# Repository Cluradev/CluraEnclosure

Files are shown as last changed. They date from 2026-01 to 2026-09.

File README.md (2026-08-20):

# CluraEnclosure

**The Clura Enclosure** is the 100% open-source, modular, and smart enclosure designed for desktop 3D printers. Developed with a focus on safety and air quality, it incorporates active filtration and smart sensors to enhance your 3D printing experience.

[Discord Community](https://discord.gg/dJDUmdvcgZ)

Clura Enclosure

## Why We Built It

The project started with me (Fabrizio), an aerospace engineering student who wanted to print in his room without compromising his safety. In fact, it is widely documented that most 3D printer filaments emit VOCs and particulate matter, which can be harmful to health. I searched for a smart, affordable, open-source enclosure but couldn't find one, so I decided to build my own. 18 months of hard work later, here we are!

## Kits

Kickstarter orders are being fulfilled. Future kit batches are being planned, but nothing is finalized yet.

You can still build the enclosure today without waiting on us. Everything here is open source and the [Bill of Materials](Documentation/README.md) lists every part with soemtimes supplier links.

The original campaign page is still up for reference: [Kickstarter](https://www.kickstarter.com/projects/clura/enclosure)

## Documentation

All project documentation, including assembly manuals and Bills of Materials (BOM), will also be published on **CluraDocs**. If you're looking to assemble your own Clura Enclosure, that is the place to go. Note: CluraDocs is still a work in progress, we are always working on improving it. If you have any suggestions or feedback, please let us know!

Check it out here: [CluraDocs](https://docs.clura.dev)

## Key Features

- **Safety & Air Quality:** Dual-layer HEPA and carbon filtration system designed to capture VOCs and UFPs.
- **Smart Controls:** Integrated 4.3" touchscreen for real-time monitoring of temperature, humidity, and air quality.
- **Modular Design:** Fully customizable hardware and software modules.
- **Open Source:** 100% open source CAD files, firmware, and guides.

Clura Enclosure Features

## Repository Structure

- `Documentation/`: Assembly manual and BOM.
- `Firmware/`: Firmware for the screen and the mainboard, plus the SD card files.
- `CAD/`: STEP models of the full enclosure, one per size (PE1, BE1, ME1).
- `PCBs/`: KiCad 9 sources for the mainboard and the sensorboard.
- `Production/`: Ready-to-use production files (laser cutting, extrusions, metal plates, PCB gerbers).
- `3D Printable Files/`: The `.3mf` files you print yourself.

In each folder there is a readme file with more info.

> For the printable parts, [CluraDocs](https://docs.clura.dev/the-build/preparations/printed-parts) has a picker that works out exactly which files and quantities your build needs.

## License

Every file in this repository is released under the **CC BY-NC (Creative Commons Attribution-NonCommercial)** license. 

For more details on the reasoning behind this choice, you can read our blog post: [The License - Clura Blog](https://www.clura.dev/blog/the-license)

---
*For more information, visit [clura.dev](https://www.clura.dev).*

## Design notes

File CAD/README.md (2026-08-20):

# CAD Models

Full assembly models for each enclosure are provided as STEP files, one per size. Fusion 360 source files are currently being refined and will be released in the near future.

These are reference models of the complete enclosure. The files you actually fabricate from live elsewhere:

- **`3D Printable Files/`** in the repository root: the `.3mf` files you print
- **`Production/`**: STEP models of every cut extrusion, DXF for the acrylic panels and metal plates, and the PCB gerbers

### Compatibility
- **PE1**: Prusa i3 MK3 / MK4
- **BE1**: Bambu Lab A1, Creality HI, Ender 3 and similar Ender-style printers
- **ME1**: Prusa Mini, Bambu Lab A1 Mini

Models

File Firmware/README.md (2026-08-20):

# Clura Enclosure - Firmware Guide

Welcome to the Clura Enclosure firmware! This guide covers everything you need to flash firmware and customize your enclosure's behavior.

---

## Quick Start

Files contained in this folder:
1. Bootloader_v1Soft - bootloader for the board, allows to easily update the firmware. All boards come pre flashed with this
2. Monitor - main firmware of the application to be flashed with an st link on the board, so if one wishes to not have the bootloader (mainly for testing)
3. MonitorBTL - main firmware of the board, flashed using monitor.bin file
4. Screen UI - contains HMI editable file, and monitorHMI.tft (to be renamed firmware.tft in order to flash the screen)
5. SD Card files - monitor.bin (file to flash the latest firmware), filament.clu (file to edit the filaments on the EEPROM, it's automatically generated by the board), data.clu (allows many parameters of the board to be adjusted, needs to be copied onto the sd card)

### Flashing Firmware

The easiest way to update your Clura Enclosure is using an SD card.

#### Main PCB Update

1. Copy your build to the root of the SD card and **name it exactly `monitor.bin`**
2. Insert the SD card into the main PCB
3. Power on the enclosure
4. Wait for the confirmation message on screen
5. The system will automatically reboot with new firmware

> **The filename matters.** The bootloader only ever looks for `monitor.bin`

The bootloader **checks the image before erasing anything**: it verifies the file
size, reads it end to end, and confirms it looks like real firmware. Only then does it
erase and program, and afterwards it verifies what was written. If any of that fails it
shows the failure page and leaves your existing firmware untouched. `monitor.bin` is deleted only after a
successful, verified update.

#### Screen Update

1. Copy `firmware.tft` to the root of your SD card (this is `monitorHMI.tft` renamed)
2. Insert the SD card into the screen
3. Power on the screen
4. Wait for flashing to complete
5. **Remove the SD card** and power cycle the screen

> **Note**: Never remove power during flashing!

---

## Customizing Your Enclosure

### The data.clu File

`data.clu` holds the enclosure's **tuning parameters** - thresholds, angles, timings.
It lets you retune a machine without rebuilding the firmware.

**Location**: Root of SD card
**Format**: Plain text, `key = value`, one per line. `#` starts a comment.

> **This file is read-only from the enclosure's point of view.** It is never written or
> updated by the machine. Your day-to-day settings (brightness, fan speeds, filament
> choice, calibration) live in the enclosure's internal memory and are **not** in this
> file. That separation is deliberate: it means the card can stay in the machine
> permanently without ever overwriting what you set on the touchscreen.

#### How it is applied: `configRevision`

Every `data.clu` starts with a revision number:

```ini
configRevision = 8
```

The enclosure remembers the last revision it applied, and only reads the file when the
number in it is **higher**. So:

* Leave the card in permanently - on a normal boot the file is ignored entirely.
* To push a change: **edit the value, raise `configRevision`, power-cycle.**
* The same card configures every machine you insert it into, once each.
* To undo a change, restore the old value **and raise the number again.** Never reuse a
  number.

A file with no `configRevision` line is ignored completely.

> **After a firmware update, leave `data.clu` on the card for the first boot.** A
> firmware update can reset the tuning block to its defaults, and the file will
> immediately re-apply itself.

#### Safety

Every value is clamped to the range shown next to it. A typo cannot disable thermal
protection or drive the servo into a mechanical stop. Keys you leave out keep their
current value; unknown keys are ignored.

#### What you can tune

**Servo / flap**

| Key | Range | Meaning |
|---|---|---|
| `servoOpenAngle` | 1-90 | Flap open position (also used for the overtemp vent) |
| `servoCloseAngle` | 1-90 | Flap closed position |
| `servoHoldMs` | 100-3000 | How long the servo is driven before it powers down |
| `servoTempHyst` | 1-10 | Hysteresis on the overtemp vent, in °C |

**Safety**

| Key | Range | Meaning |
|---|---|---|
| `maxTemp` | 35-80 | Temperature that forces the flap open, in °C |
| `opticalAlarmEnable` | 0-1 | `0` = the optical smoke sensor is ignored |
| `smokeFireResponse` | 0-1 | `1` = on smoke, all fans stop and the flap closes |
| `lpgThreshold` | 100-4095 | MQ2 gas trigger level |
| `smokeThreshold` | 100-4095 | MEMS smoke trigger level |
| `smokeBeginTime` | 0-900000 | Warm-up before the alarm arms, in ms |

**Fans**

| Key | Range | Meaning |
|---|---|---|
| `autoCoolTempMin` / `autoCoolTempMax` | 0-60 | Cooling fan ramp, in °C |
| `autoFilterImpMin` / `autoFilterImpMax` | 0-1000 | Filter fan ramp on PM2.5 |
| `autoFilterP03Min` / `autoFilterP03Max` | 0-10000 | Filter fan ramp on PM0.3 |
| `extraFanSpeed` | 0-100 | Fixed speed of the extra fan when switched on, in % |

**Intervals and display**

| Key | Range | Meaning |
|---|---|---|
| `bmeSampleInterval` | 1000-60000 | Time between temperature/VOC readings, in ms |
| `usageLogInterval` | 60000-3600000 | How often the usage counter is saved, in ms |
| `sensorUsageWarnHours` | 0-20000 | Runtime **hours** before the "replace sensor" icon |
| `minBrightness` | 5-100 | Lowest screen brightness the UI will allow |
| `countdownTime` | 1-60 | Calibration "continue" countdown, in seconds |

**Load-cell factory seeds**

`defaultLeftCal`, `defaultRightCal`, `defaultLeftOffset`, `defaultRightOffset`,
`tareWeight`.

These are only used by a machine that has **never** completed calibration. Once a unit
is calibrated it keeps its own measured values forever, and changing these will not
disturb it. They are also what the "restore defaults" button writes back.

---

## How Key Features Work

### The Flap

The flap is controlled by the **OPEN/CLOSE button on the fan page**. 

Each press drives the servo to the new position and then **powers it down** after
`servoHoldMs`. This is intentional: it stops the servo buzzing and drawing current
while holding position.

Two safety rules override the button, in this order:

1. **Smoke detected** → the flap **closes**
2. **Temperature above `maxTemp`** → the flap **opens**

Smoke deliberately outranks temperature. A fire raises the temperature too, so without
that ordering the enclosure would vent the fire while trying to starve it.

### Automatic Cooling

When auto cooling is enabled, the cooling fan follows the temperature:

- **At or below `autoCoolTempMin` (20 °C)**: fan off
- **Between the two**: fan speed increases linearly
- **At or above `autoCoolTempMax` (40 °C)**: fan at 100%

### Automatic Filtering

When auto filtering is enabled, the filter fan follows air quality:

- Monitors **PM2.5** and **PM0.3** particle counts
- Uses whichever indicates worse air
- Below both thresholds the fan is **off**, not idling
- Once either threshold is crossed it starts at **20%** and ramps to 100% with
  concentration, so there is a step from 0% to 20% at the threshold

PM1 and PM10 are measured and written to the log, but they do not affect fan speed.

### Overtemperature

If the temperature passes `maxTemp` **and there is no smoke**:

- The flap **opens** and is held open
- **Every fan runs at 100%** to pull the heat out

It returns to normal once the temperature drops below `maxTemp - servoTempHyst`. This
needs the BME sensor enabled - with no temperature source there is nothing to act on.

### Fire Alarm

Two sensors can raise the alarm by default:

1. **MQ2 gas sensor** - LPG, propane, smoke
2. **MEMS sensor** - smoke

A third, the **optical smoke sensor, is disabled by default** (`opticalAlarmEnable = 0`).
Its input is pulled high and reads "smoke" when nothing is connected, so an absent or
faulty sensor would hold the alarm on permanently. Enable it only once a working sensor
is fitted, and check that it reads clear when idle.

The alarm has a warm-up period after power-on (`smokeBeginTime`) to avoid false trips
while the gas sensors heat up.

When triggered:

- **Buzzer sounds** (unless muted)
- **LED strip turns red** (if the alarm indicator is enabled)
- **Every fan stops** and **the flap closes** - so the enclosure is not feeding oxygen
  to a fire or pushing smoke out through the filter

Muting only silences the buzzer. It does **not** restart the fans or reopen the flap.

---

## Spool Holder System

The dual spool holders track filament weight in real time using load cells.

### How It Works

1. **Calibrate the load cells** (one-time setup via touchscreen)
2. **Select your filament brand** from the list, or add a custom one
3. The system shows: `Remaining Filament = Current Weight - Empty Spool Weight`

With an empty holder the display shows the **negative spool weight** - for example
`-202` when a 202 g spool is selected. That is normal, and tells you at a glance both
that the holder is empty and which spool is configured.

`-404` means the load cell is not responding or is disabled, not a weight.

### Filament Profiles

The enclosure ships with 16 preset filament brands and has room for **24 in total**, so
you can add 8 of your own. Each entry stores a brand name and an empty spool weight in
grams. The library lives in the enclosure's memory and is mirrored to `filament.clu`
on the SD card.

### Adding Custom Filament

Via the touchscreen calibration menu:

1. **Tare**: remove the spool and zero the scale
2. **Weigh**: place a **full** spool to measure the total weight
3. **Name**: enter the brand name
4. **Save**: the profile is stored and `filament.clu` is updated

> The empty-spool weight is worked out as *measured weight − `tareWeight`*, where
> `tareWeight` (default 1000 g) is the assumed weight of the filament itself. **Use a
> full, unused spool** - a partly used one gives a wrong result.

### The filament.clu File

Unlike `data.clu`, this file works **both ways**:

- If it is missing, the enclosure **creates it** from its current library
- Whenever you register a spool on the machine, the file is **rewritten** to match
- If you edit the file and raise `filamentRevision`, the enclosure **imports** it

```ini
filamentRevision = 3
filamentCount    = 17

filament0  = Sunlu,134
filament1  = Prusament,198
filament16 = My Custom PLA,205
```

To add a spool by hand: add a `filament<n>` line and **raise `filamentRevision`**. The
number of entries is worked out from the highest `n` present, so you do not have to
touch `filamentCount`.

> `filamentRevision` must be **higher** than the number the machine last applied, or the
> file is ignored. In practice the number in the file is the applied one, because both an
> import and an export leave the two in step, so read it and go above it. Note the file is
> only rewritten when it is missing at boot or when you register a spool on the
> touchscreen - it is not refreshed on every ordinary boot.

> One card shared between machines with different custom spools will end up holding
> whichever machine wrote last. Raise the revision to make one library authoritative.

---

## Advanced Configuration

### Compile-Time Settings (parameters.h)

Most tuning is now done through `data.clu` and needs no rebuild. The values in
`Core/Inc/parameters.h` are the **defaults** used when a machine has no tuning stored -
`data.clu` overrides them.

You only need to rebuild for things that are not tunable, such as screen page IDs,
image IDs, or the number of filament slots.

To change a default: edit `parameters.h`, rebuild in STM32CubeIDE, and reflash.

---

## Data Logging

Enable logging via the touchscreen to track environmental data over time.

**Log File**: `log.csv` on SD card

**Columns**:

```
BootID, MinSinceBoot, Temperature, Humidity, Pressure, Smoke,
PM 0.3, PM 2.5, PM 10, VOC, LPG, Fan Speed, Left Weight, Right Weight
```

`BootID` counts power-on sessions and `MinSinceBoot` is minutes since that power-on.
The enclosure has no real-time clock, so sorting by **BootID then MinSinceBoot** gives
you correct chronological order across reboots.

Two columns are easy to misread:

* **`Pressure` is in Pascals**, straight from the BME680, so a normal sea-level reading is
  about 101325 rather than 1013. Divide by 100 for hPa or mbar.
* **`VOC` is not a gas resistance.** It is an air-quality score computed from the BME680's
  gas reading and the humidity, on a 0-500 scale where **lower is better**. It is scored
  against a rolling internal reference, so it is meaningful over time on one machine rather
  than as an absolute figure to compare between machines.

**Intervals**: 5, 10, or 60 minutes.

The file is only appended to, so it can grow indefinitely - roughly 18 KB per day at the
5-minute interval.

---

## Machine Usage Counter

The enclosure counts hours of **filter-fan runtime** and shows a "replace sensor" icon
once it passes `sensorUsageWarnHours` (default 600 h). Both automatic and manual
filtering count toward it. It can be reset from the settings page.

---

## Troubleshooting

**SD Card Not Recognized**
- Format as FAT32 (exFAT is not supported)
- Insert before powering on
- Check for physical damage

**Firmware Update Does Nothing**
- The file must be named exactly `monitor.bin`
- Check you copied the newest build - confirm its timestamp

**Firmware Update Shows the Failure Page**
- The image was rejected before anything was erased; your firmware is intact
- Usually a corrupted or incomplete copy - copy `monitor.bin` again

**Sensors Not Working**
- Verify connections
- Enable the sensor in the Features menu
- Check the System Check page for sensor status

**Load Cells Inaccurate**
- Recalibrate via the touchscreen
- Tare with an empty holder
- Check for mechanical interference

**Spool Shows -404**
- The load cell is not responding, or load cells are disabled in Features

**Added a Spool to filament.clu but Cannot Select It**
- Raise `filamentRevision` - without that the file is not read at all

**Changed data.clu but Nothing Happened**
- Raise `configRevision`. The file is only read when the number increases

**False Fire Alarms**
- Wait out the warm-up period after power-on (`smokeBeginTime`)
- Check the readings on the Sensors page
- If the optical sensor was enabled, confirm it reads clear when idle - an unconnected
  sensor reads as permanent smoke
- Adjust `lpgThreshold` / `smokeThreshold` in `data.clu`

**Fans Will Not Run**
- Check whether the alarm is active - smoke stops every fan by design

---

## Support

For more information, visit [clura.dev](https://www.clura.dev)

*Last Updated: August 2026*

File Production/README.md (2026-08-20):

# Production Files

Everything needed to have the enclosure parts made. Files are split in two groups:

* **Enclosure Size Specific Parts** holds the parts that change with the enclosure size (PE1, BE1, ME1)
* **General Parts** holds the parts that are the same on every size

Each file name starts with the quantity needed, for example `2x_` means two pieces. Acrylic and sheet metal file names also carry the thickness and the material colour.

---

## Folder tree

```
Production
│
├── Enclosure Size Specific Parts
│   │
│   ├── PE1                          Prusa size enclosure
│   │   ├── AcrylicPE1
│   │   │   ├── DXF                  cutting files for the laser shop
│   │   │   └── Drawings             PDF drawings of the same panels
│   │   ├── BottomMetalPlatePE1      DXF, STEP and PDF for the steel bottom plate
│   │   └── ExtrusionsPE1
│   │       ├── Step                 3D models of every cut extrusion
│   │       └── Drawings             PDF drawings with lengths, taps and holes
│   │
│   ├── BE1                          Bambu size enclosure
│   │   ├── AcrylicBE1
│   │   │   ├── DXF
│   │   │   └── Drawings
│   │   ├── BottomMetalPlateBE1
│   │   └── ExtrusionsBE1
│   │       ├── Step
│   │       └── Drawings
│   │
│   └── ME1                          Mini size enclosure
│       ├── AcrylicME1
│       │   ├── DXF
│       │   └── Drawings
│       └── ExtrusionsME1
│           ├── Step
│           └── Drawings
│
└── General Parts
    │
    ├── Electronics
    │   ├── CircuitBoards
    │   │   ├── Mainboard
    │   │   │   ├── GBR              gerbers and drill files
    │   │   │   ├── CPL              pick and place position files
    │   │   │   └── BOM_FINAL_MAINBOARD.xlsx
    │   │   └── Sensorboard
    │   │       ├── GBR
    │   │       ├── CPL
    │   │       └── BOM_FINAL_SENSORBOARD.xlsx
    │   └── CablesDrawings           drawings for the four custom cables
    │
    └── MagneticPlates               0.5 mm steel plates for the screen and the filters
```

> The `.3mf` files you print yourself are **not** in this folder. They live in
> **`3D Printable Files/`** in the repository root.

---

## What is inside

### Enclosure Size Specific Parts

Three sizes are available. Pick the folder that matches your enclosure and use only the files inside it.

| Folder | Enclosure |
| --- | --- |
| PE1 | Prusa size |
| BE1 | Bambu size |
| ME1 | Mini size |

**Acrylic**
`DXF` holds the flat cutting profiles, one file per panel type. Send these to the laser cutting shop. `Drawings` holds the matching PDF drawings so you can check dimensions and part count before ordering. Clear panels are 4 mm, black electronics panels are 3 mm.

**Extrusions**
All parts use 2020 aluminium profile. `Step` holds the 3D model of each cut length, `Drawings` holds the PDF with the length, the tapped ends and the drilled holes. The `2020R` files are the rounded profile version. (they are not essential)

**Bottom metal plate**
1.5 mm steel plate, supplied as DXF for cutting, STEP for reference and PDF for checking. Available for PE1 and BE1. 

### General Parts

**Electronics**
Two boards, the Mainboard and the Sensorboard. Each one has a `GBR` folder with the gerbers and the drill files, a `CPL` folder with the component positions for the assembly house, and a BOM spreadsheet. This is the full package most PCB manufacturers ask for.

**Cables Drawings**
Inside `Electronics/CablesDrawings` there are PDF drawings for the four cables that are not off the shelf: the PMS5003 particle sensor cable, the screen cable, the sensorboard cable and the smoke sensor cable. Use these when ordering from a cable assembly shop.

**Magnetic Plates**
Thin 0.5 mm steel plates that the magnets hold on to. Three screen plates (left, right, top) and two filter plates. Supplied as DXF.

---

## Elsewhere in the repository

* **`3D Printable Files/`** - the `.3mf` files for the parts you print yourself.
  [CluraDocs](https://docs.clura.dev/the-build/preparations/printed-parts) works out which
  ones your build needs.
* **`PCBs/`** - KiCad 9 sources for the mainboard and the sensorboard, if you want to modify
  them rather than just have them made.

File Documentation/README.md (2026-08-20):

# Project Documentation

Welcome to the project documentation repository. Below are the primary resources for tracking progress and assembly instructions.

## Key Resources

*   **Assembly Manual:** [PDF](Manual/Assembly%20Manual%20Clura%20Enclosure.pdf) - [PowerPoint source](Manual/Assembly%20Manual%20Clura%20Enclosure.pptx) - [live version](https://docs.google.com/presentation/d/1gN7Vz8oDnyvjdDaU4doY_BvzhIG2yaButCSMbnnlYWI/edit?usp=sharing)
*   **Bill of Materials:** [Spreadsheet](BOM/Final_BOM_Clura_Enclosure.xlsx) - [live version](https://docs.google.com/spreadsheets/d/1zxFBzsFjeg29lGvyA2hwyYCAKZ0MYmlyk_qqRtMol1E/edit?usp=sharing)
*   **Assembly Guide:** [CluraDocs - Assembly Section](https://docs.clura.dev/the-build/assembly)

Assembly

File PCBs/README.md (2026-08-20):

# Mainboard + Sensorboard

Open hardware KiCad 9 designs for a two-board set: an STM32F411-based **mainboard**
that handles power, control and I/O, and a companion **sensorboard** carrying the
gas/smoke sensing front end. The two connect over an RJ45 link.

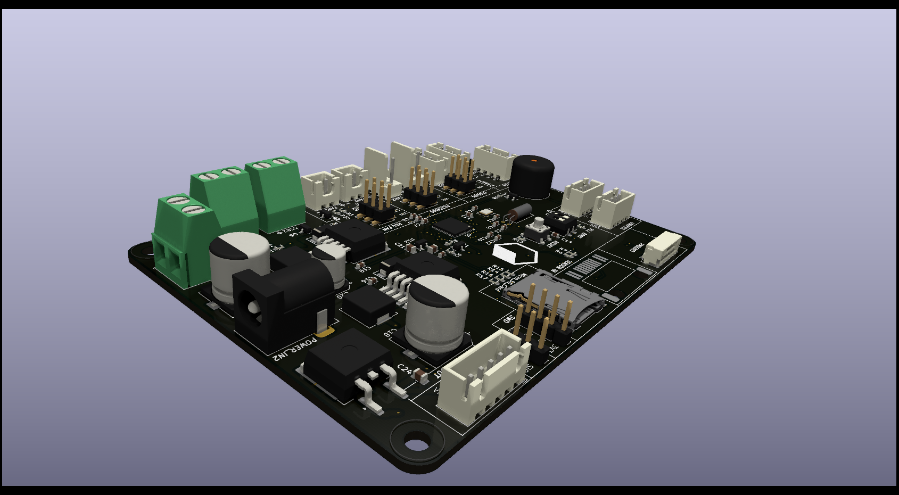
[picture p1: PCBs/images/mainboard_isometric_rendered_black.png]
Mainboard


## Boards

| | Mainboard | Sensorboard |
|---|---|---|
| Size | 120.05 × 90.05 mm | 73.04 × 50.07 mm |
| Copper layers | 4 (F.Cu, In1 GND, In2 VIN, B.Cu) | 2 (F.Cu, B.Cu) |
| Thickness | 1.6 mm | 1.6 mm |
| Placements | 174 | 22 |
| Revision | Rev-B | Rev-B |

### Mainboard

- **MCU** — STM32F411CEU6, 25 MHz HSE + 32.768 kHz LSE crystals, SWD header, BOOT jumper
- **Storage** — micro SD card slot, AT24CS64 I²C EEPROM
- **Power** — 12 V input via barrel jack / screw terminal, LM2596 switchers for 12 V and 5 V rails,
  SY8120B for 3V3, dedicated +5 V servo rail, fuse and reverse-protection diode
- **I/O** — RJ45 to the sensorboard, HX711 load-cell interface, PMS5003 particulate sensor header,
  three fan channels (60 mm, 140 mm, regulator fan) with MOSFET drive and tach/PWM,
  servo output, 5 V SSR terminal, WS2811 LED strip, buzzer, display header, DHT11, DIP + push switches
- **Protection** — PESD/BSD TVS arrays on the exposed interfaces

### Sensorboard

- MEMS smoke sensor, electrochemical smoke sensor and an optical channel
- LM317 (SOT-223) and SSP7901P33MR regulation
- WS2811 addressable LED
- RJ45 back to the mainboard, screw terminal sensor output, jumper-selectable options

## Repository layout

```
kicad/                  KiCad 9 source — open a .kicad_pro here
  mainboard.kicad_pro / .kicad_sch / .kicad_pcb
  sensorboard.kicad_pro / .kicad_sch / .kicad_pcb
  SensorBoard.kicad_sch    shared hierarchical sub-sheet
  power.kicad_sch          shared hierarchical sub-sheet
  3dmodels/                see note below
3d/mainboard.step          assembled 3D model
images/                    board renders
```

## Opening the projects

Both projects target **KiCad 9.0**. Open `kicad/mainboard.kicad_pro` or
`kicad/sensorboard.kicad_pro`. All symbols and footprints are cached inside the
`.kicad_sch` / `.kicad_pcb` files, so the boards render and plot correctly on a
stock KiCad install with no extra libraries.

A handful of symbols and footprints originate from custom libraries
(`custom_Library`, `custom`, `board`, `CustomFootprint`, `PESD5V0S1BA`,
`74HCT1G125GW`). Those libraries are not part of this repository, so KiCad will
report them as missing if you use *Update Symbols/Footprints from Library*. Normal
editing, plotting and DRC are unaffected.

## Manufacturing

Go to the production folder in the main repo.

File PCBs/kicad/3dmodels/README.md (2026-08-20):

# Third-party 3D models

Two models referenced by `mainboard.kicad_pcb` are not redistributed here:

| File | Used by |
|---|---|
| `PESD3V3L1BA.step` | 23 TVS diode placements |
| `NCV68061SOP95P275X110-6N.step` | 1 ideal-diode controller |

Drop them into this directory to restore the complete 3D view. Everything else
resolves from the stock KiCad 3D model library via `${KICAD9_3DMODEL_DIR}`.

The original design referenced these two through absolute paths on the author's
machine; those paths were replaced with `${KIPRJMOD}/3dmodels/` so the project
contains no machine-specific locations.

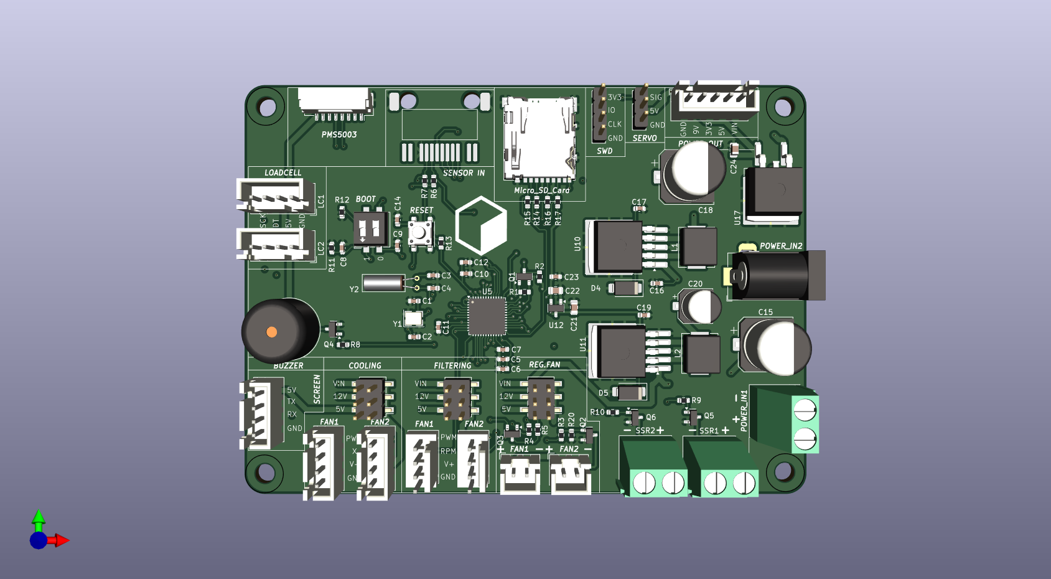
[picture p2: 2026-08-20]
PCBs/images/mainboard_top.png

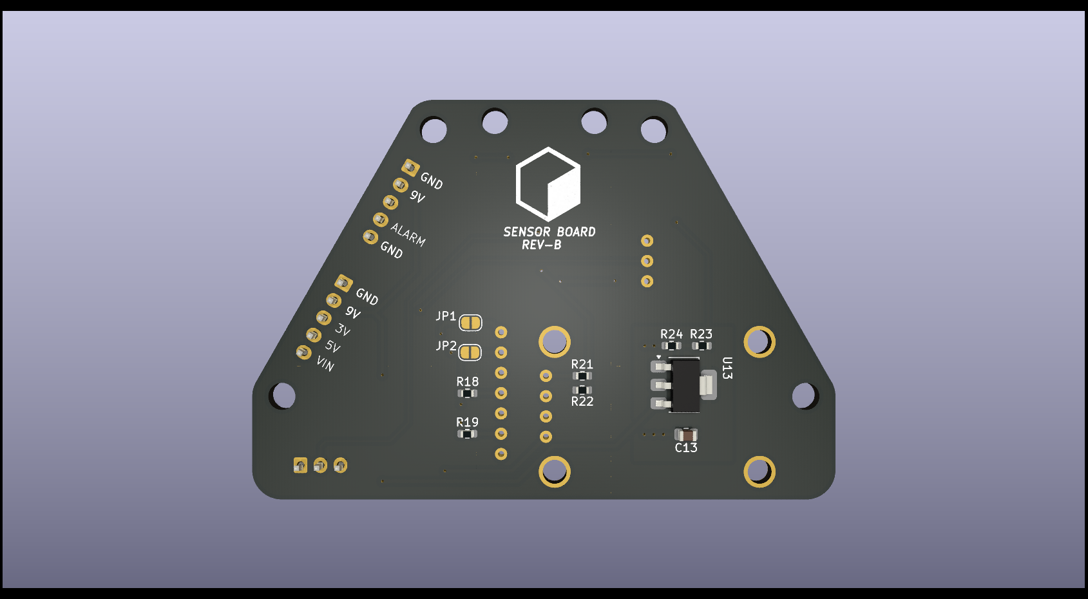
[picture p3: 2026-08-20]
PCBs/images/sensorboard_bottom_rendered_black.png

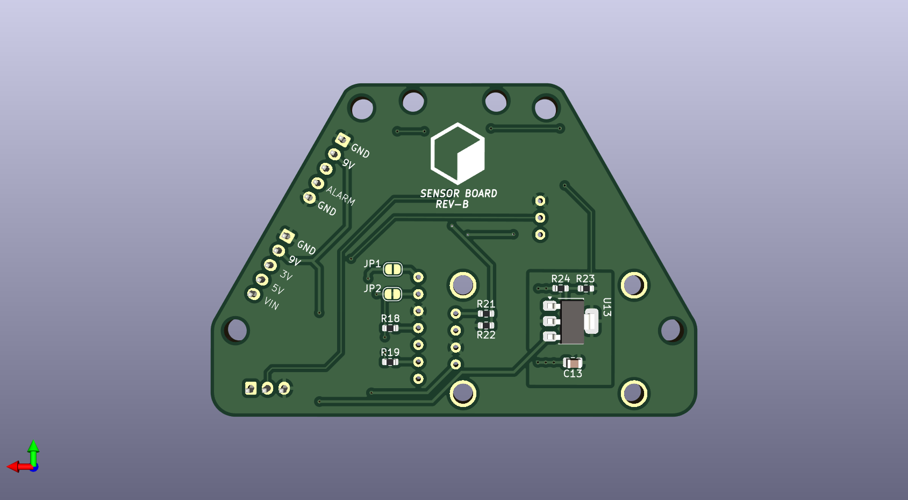
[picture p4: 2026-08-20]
PCBs/images/sensorboard_bottom.png

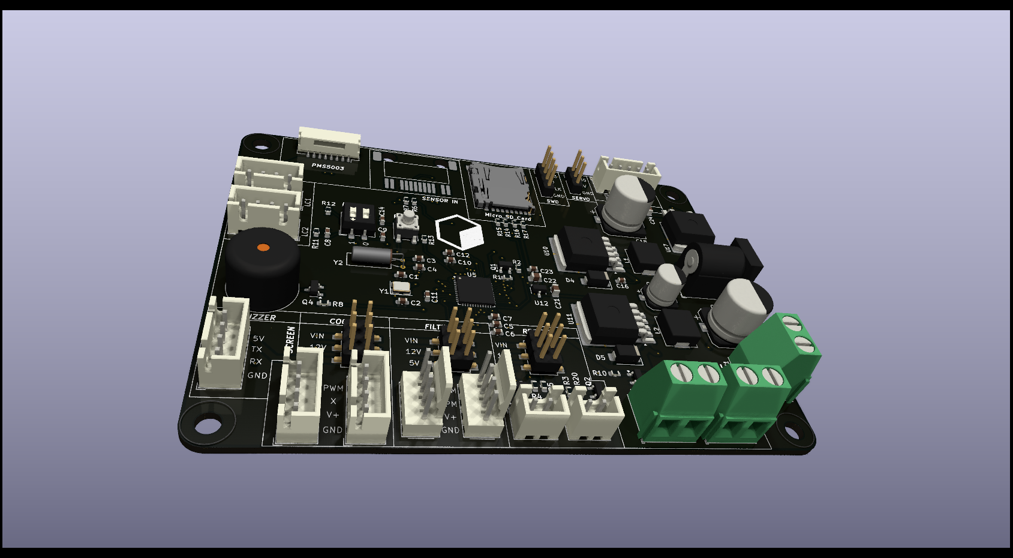
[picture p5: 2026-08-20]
PCBs/images/mainboard_front_rendered_black.png

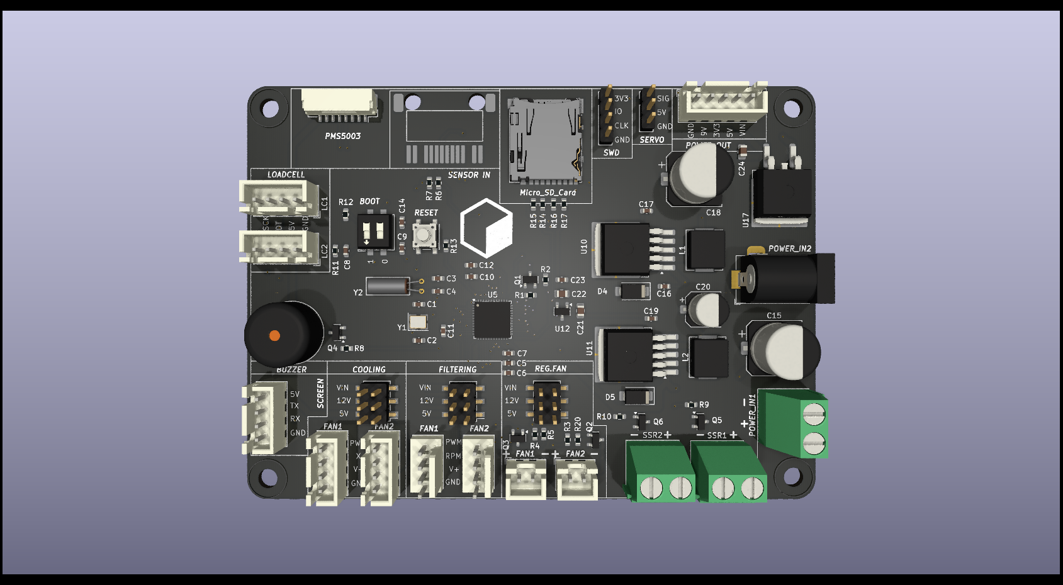
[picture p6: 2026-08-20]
PCBs/images/mainboard_top_rendered_black.png

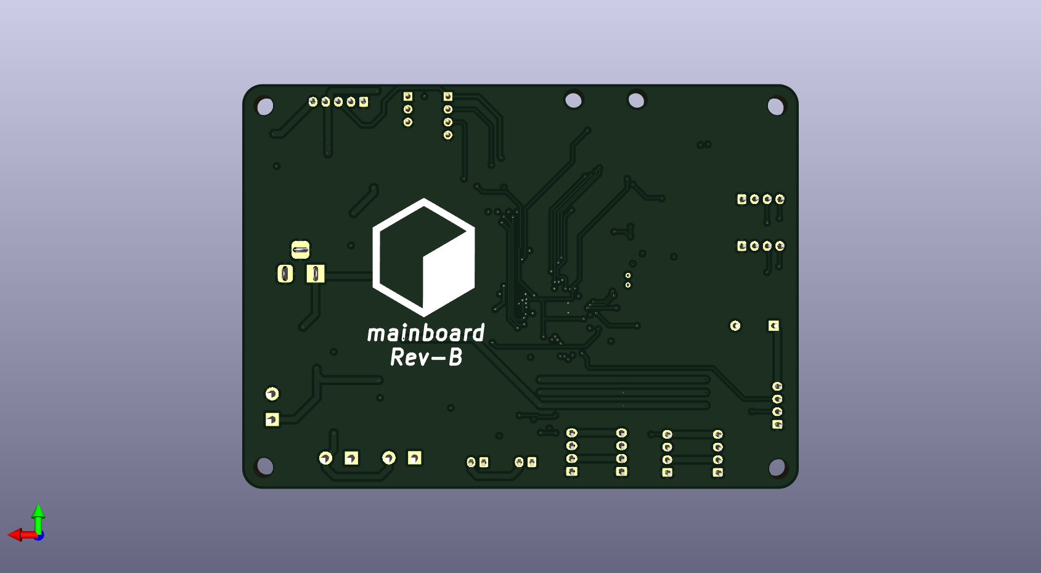
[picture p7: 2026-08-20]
PCBs/images/mainboard_bottom.png

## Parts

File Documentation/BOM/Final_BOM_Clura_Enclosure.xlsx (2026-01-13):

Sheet: BOM BE1_Pro
Part | Details | Print time | Quantity | Img | Links
2020R Extrusion 620 | Length 620mm, machining necessary, M5x15 Taps on both ends |  | 4
2020 Extrusion 520 | Length 520mm, machining necessary, M5x15 Taps on both sides |  | 6
2020 Extrusion 670 | Length 670mm, machining necessary, M5x15 Taps on both sides |  | 4
2020 Extrusion 580 | Length 580mm, machining necessary, M5x15 Taps on both sides |  | 2
Top_Panel_Plate | Material: Ferrous metal (Iron), 0.5mm thick with double sided adhesive on back |  | 1
Filters_Plate | Material: Ferrous metal (Iron), 0.5mm thick with double sided adhesive on back |  | 2
Left_Screen_Plate | Material: Ferrous metal (Iron), 0.5mm thick with double sided adhesive on back |  | 1
Right_Screen_Plate | Material: Ferrous metal (Iron), 0.5mm thick with double sided adhesive on back |  | 1
Side Panels FS | 4mm Acrylic |  | 2
Door Panel FS | 4mm Acrylic |  | 2
Top Panel FS | 4mm Acrylic |  | 1
Back Panel FS | 3mm Acrylic |  | 1
Top Panel electronics | 3mm Acrylic |  | 1
Back Panel electronics | 3mm Acrylic |  | 1
Side Panel electronics | 3mm Acrylic |  | 2
M2x8 Self tapping | Stainless steel 304 or 316 |  | 5
M3x8 Self tapping BHCS | Stainless steel 304 or 316 |  | 150
M3x8 Self tapping FHCS | Stainless steel 304 or 316 |  | 20
M3x10 BHCS | Stainless steel 304 or 316 |  | 80
M3x20 SHSS | 4mm shoulder diameter, 6mm thread length, 20mm shoulder length |  | 10
M3 hammerhead nut | Stainless steel 304 or 316 |  | 80
M3 t nut | Stainless steel 304 or 316 |  | 10
M4x20 BHCS | Stainless steel 304 or 316 |  | 10
M4x16 Self tapping | Stainless steel 304 or 316 |  | 25
M5x16 BHCS | Stainless steel 304 or 316 |  | 60
M5 Hammerhead nut | Stainless steel 304 or 316 |  | 30
Main Board | STM32, Controls everything |  | 1
Sensor Board | Sensors as boards |  | 1
MQ2 Smoke sensor | Smoke/combustion gas sensor, straight pins |  | 1 |  | https://www.aliexpress.com/item/32328262269.html
Optical smoke sensor | Optical smoke sensor (elecbee) |  | 1 |  | https://www.elecbee.com/en/product-detail/dc-9v-photoelectric-smoke-sensor-module-smoke-detector-smoke-sensor-probe-module_25004
MEMS Smoke Sensor | Pre soldered pins |  | 1 |  | https://www.dfrobot.com/product-2698.html
BME 680 Sensor Module | gas (VOC), pressure, humidity and temperature sensor |  | 1 |  | https://www.aliexpress.com/item/1005006566621294.html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
PMS 5003 | PM2.5 particle sensor |  | 1 |  | https://www.aliexpress.com/item/1005005967735332.html
HX711 modules and load cells | 5kg load cell, Load cell cable length 150mm, output cable length 1.3m (JST XH2.54) |  | 2 |  | Use the ones we already have
1.55M Led strip | RGB WS2811 6x12mm (neon type) 6mm wide, 12mm high, JST XH2.54 connector |  | 1 |  | https://it.aliexpress.com/item/1005007529227200.html
TJC 4.3 inch display | TJC8048X543_011C |  | 1
24v 4a PSU | 5.5x2.1 (connector size dc jack) - Double check that it fits in the board |  | 1
Ethernet Cable (Rj45) | 1.5meter - Cat 5e or cat 6 is ok |  | 1
Dc jack port | 5.5x2.1 (connector size dc jack), 30cm cable |  | 2 |  | https://it.aliexpress.com/item/1005005889554877.html
6025 24v PWM | Generic model is fine, MF60252VX-1E01C-S99 |  | 1 |  | https://www.aliexpress.com/item/32862233809.html
MG996 Servo | 50cm cable |  | 2
Servo cable spliiter | Join the two servo cables to be controlled by one input |  | 1 |  | aliexpress.com/item/1005005668365916.html
Cable AMS lite extension | 50cm or 100cm is fine |  | 1 |  | aliexpress.com/item/1005007598457475.html
Cable Screen | See drawing - jst 4pin |  | 1
Cable SensorBoard | See drawing - jst 5pin |  | 1
Cable PMS5003 | See drawing - 1mm pitch |  | 1
Cable Elecbee | See drawing - jst 5pin |  | 1
12032 Fans | PWM capability, Quiet |  | 2
Hepa carbon filter | 130x130x60mm |  | 2
Countersunk Magnets | 40x10x4mm, M3 |  | 1
Countersunk Magnets | 3x14mm, M3 |  | 12 |  | https://it.aliexpress.com/item/1005003830767173.html
Cable passthrough cover | 50mm diameter hole |  | 4 |  | https://it.aliexpress.com/item/1005006299941832.html
PC Dust filter magnetic | 80mm version |  | 2 |  | https://it.aliexpress.com/item/1005006442730197.html
Ptfe tube 4x2mm | 0.9 meter Spool holders to A1 |  | 2
Ptfe tube 4x2mm | 1.05 meter AMS |  | 4
Ptfe tube 4x2mm | 95mm - for spool holders sliding |  | 4
PC4 M6*1 fitting - 4.1 mm bore | For spool holders |  | 6
Phone holder metal plates | 30mm diameter |  | 12 |  | https://it.aliexpress.com/item/1005006955575428.html
Window foam 8mmX1.5mm | 8mm wide, 1.5mm high, 5 meters long |  | 1 |  | https://it.aliexpress.com/item/32894535153.html
Allen Keys 2,2.5,3,4mm | Colored allen keys for easy installation |  | 1
Torx driver -size 10
Foam |  |  | 1
Cardboard box electronics | 160x160x40mm OUTSIDE dimensions |  | 4
Cardboard box screen | 100x160x40mm OUTSIDE dimensions |  | 1
Cardboard box psu | 100x180x40mm OUTSIDE dimensions |  | 1
Carton |  |  | 1

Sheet: Screw Distribution
Component | Screws | Quantity | Type | Quantity
Lighting | M3x8 Self tapping | 27 | M2x8 Self tapping | 2
 |  |  | M3x8 Self tapping | 116
Front Panel | M3x10 BHCS | 9 | M3x10 BHCS | 66
 | M3 T nut | 9 | M3x8 FHCS Self tapping | 12
 | M3x8 Self tapping | 12 | M3x20 SHCS | 8
 | M3x20 SHCS | 4 | M3 T nut | 66
Screen Assembly | M5x16 BHCS | 2 | M4x20 BHCS | 4
 | M5 T nut | 2 | M4x45 BHCS | 0
 | M3x8 FHCS Self tapping | 4 | M4x16 Self tapping | 18
 | M3x8 Self tapping | 5 | M5x16 BHCS | 45
Spool Assembly | M5x16 BHCS | 8 | M5 T nut | 15
 | M5 T nut | 4
 | M3x8 Self tapping | 4
 | M4x20 BHCS | 4
Top Panel | M3x8 Self tapping | 8
 | M3x20 SHCS | 2
 | M3x10 BHCS | 4
 | M3 T nut | 4
Side panels | M3x10 BHCS | 24
 | M3 T nut | 24
 | M5x16 BHCS | 4
 | M5 T nut | 4
Filter assembly 140mm fans | M4x20 BHCS | 4,
 | M5x16 BHCS | 2,
 | M5 T nut | 2,
 | M4x45 BHCS | 8,
Sensor Casing | M3x8 Self tapping | 4
 | M2x8 Self tapping | 2
AMS Mount | M5x16 BHCS | 5
 | M5 T nut | 3
Cable passthrough Panel | M3x8 Self tapping | 10
Cable passthrough Side | M3 T nut | 4
 | M3x8 FHCS Self tapping | 2
 | M3x10 BHCS | 4
Back Panel | M3 T nut | 3
 | M3x10 BHCS | 3
Top panel electronics | M3x10 BHCS | 4
 | M3 T nut | 4
Side Panel electronics | M3x10 BHCS | 4
 | M3 T nut | 4
 | M3x8 FHCS Self tapping | 2
Back Panel electronics | M3x10 BHCS | 8
 | M3 T nut | 8
 | M3x8 FHCS Self tapping | 4
 | M3x8 Self tapping | 4
Electronics | M3x8 Self tapping | 4
 | M3x10 BHCS | 2
 | M3 T nut | 2
Frame | M5x16 BHCS | 24
Bed cable passage | M4x16 Self tapping | 2
Filter assembly | M4x16 Self tapping | 16
 | M5x16 BHCS | 2
 | M5 T nut | 2
 | M3x8 Self tapping | 38
 | M3x20 SHCS | 2
Bottom Risers | M3x10 BHCS | 4
 | M3 T nut | 4

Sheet: Wiring harness
Component | Component type | Connects to | Connector on component | Pin num | Type | Connector on board | Length of cable (cm) | Notes
STM32F411CEU6 | SMD | Main Pcb |  |  | N/a |  | 0
MQ2 Smoke sensor | Module | Sensor Board | Header pins 2.54 | 4 | Male |  | 0
BME 680 Sensor | Module | Sensor Board | Header pins 2.54 | 7 | Male |  | 0
MAX30105 sensor | Module | Sensor Board | Header pins 2.54 | 5 | Male |  | 0
Optical smoke sensor | Standalone | Sensor Board | JST SH 1mm | 5 | Male |  | 10
WS2811 Led strip | Standalone | Sensor Board | XH2.54mm | 3 | Female |  | 10
PMS 5003 | Standalone | Main Pcb | GH 1.25mm | 8 | Male |  | 50
DHT22 | Standalone | Main Pcb | Header pins 2.54 | 3 | Male |  | 50
HX711 modules | Standalone | Main Pcb | XH2.54mm | 4 | Female |  | 100
5Kg Load cells | Standalone | Standalone | Bare wires. (solder to hx711) | 2024-04-06 | N/a |  | 15
Beeper | SMD | Main Pcb | Straight Pins | 2 | N/a |  | 0
TJC 4.3 inch display | Standalone | Main Pcb | XH2.54mm | 4 | Male |  | 50
140mm Fans | Standalone | Main Pcb | Molex KK-254 | 4 | Female |  | 50
60mm fans | Standalone | Main Pcb | XH2.54mm | 4 | Female |  | 50
24v 4a PSU | Standalone | Main Pcb | Dc Jack / Spade connectors | 2 | Male |  | 100
Connector Left end | Connector Right end | Num wires | Length (cm) | Gauge (awg) | Qty | Notes
JST SH 1mm - Female | JST SH 1mm - Female | 5 | 10 | 28 | 1 | Smoke sensor
GH 1.25mm - Female | GH 1.25mm - Female | 8 | 80 | 28 | 1 | PMS sensor
XH2.54mm - Female | XH2.54mm - Female | 4 | 150 | 28 | 1 | Screen
Ethernet cat 5e | Ethernet cat 5e | n/a | 100 | n/a | 1 | Sensor board
Soldered to hx711 | XH2.54mm - Female | 4 | 100 | 28 | 2 | Scale

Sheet: Power consumption
Object | V_in | I_in | Power
Led | 24 | 1.2 | 28.8
12032 Fans | 24 | 0.4 | 9.6
60mm Fan | 24 | 0.1 | 2.4
PMS5003 | 5 | 1 | 5
MEMS | 5 | 0.2 | 1
BME680 | 5 | 0.2 | 1
MQ2 | 5 | 0.2 | 1
Smoke sensor optical | 5 | 0.5 | 2.5
4.3 inch screen | 5 | 2 | 10
 |  |  | 0
 | Total Power | 61.3

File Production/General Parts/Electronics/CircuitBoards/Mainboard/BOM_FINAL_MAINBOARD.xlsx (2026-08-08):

Designator | Footprint | Quantity | Part #
CONN1 | RJ45_NEW | 1 | RJ45_NEW
D9,D3,D10,D1,D5,D15,D21 | SOD323 | 7 | BSD3A311V
RV1 | JST_XH_B3B-XH-A_1x03_P2.50mm_Vertical | 1 | BX-XH2.54-3PZZ-R (https://www.lcsc.com/product-detail/C22388499.html?s_z=n_BX-XH2.54-3PZZ)
D25,D4 | SOD323 | 2 | PESD12VS1UA.
C9,C7 | C_0603_1608Metric | 2 | CC0603CRNPO9BN6R0 (https://www.lcsc.com/product-detail/Multilayer-Ceramic-Capacitors-MLCC-SMD-SMT_YAGEO-CC0603CRNPO9BN6R0_C130125.html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)
R25,R19,R36,R18,R21,R39,R33,R20,R37,R38,R26 | R_0603_1608Metric | 11 | 0603WAF220JT5E
TB3 | TerminalBlock_Phoenix_MKDS-1,5-2-5.08_1x02_P5.08mm_Horizontal | 1 | WJ500V-5.08-2P (https://www.lcsc.com/product-detail/Screw-Terminal-Blocks_Ningbo-Kangnex-Elec-WJ500V-5-08-2P_C8465.html)
U3,U12,U1,U5,U4,U8,U2 | SOT-666 | 7 | USBLC6-2P6
R29,R46,R30,R24,R28,R47,R7,R4,R32,R22,R31,R11 | R_0603_1608Metric | 12 | RT0603FRE1310KL (https://www.lcsc.com/product-detail/Chip-span-style-background-color-ff0-Resistor-span-Surface-Mount_YAGEO-RT0603FRE1310KL_C4226066.html)
D14,D7,D22,D20,D17,D23,D16,D2,D12,D6,D13 | SOD323 | 11 | PESD5V0S1UA
M2,M1 | PinHeader_1x03_P2.54mm_Vertical | 2 | 2.54-1*3 (https://www.lcsc.com/product-detail/Pin-Headers_ZHOURI-2-54-1-3_C5116482.html?s_z=n_2.54-1%2A3)
U22 | SOT23-6 | 1 | SY8120B
SD1 | microSD_HC_Hirose_DM3AT-SF-PEJM5 | 1 | DM3AT-SF-PEJM5 (https://www.lcsc.com/datasheet/lcsc_datasheet_2410121938_HRS-Hirose-DM3AT-SF-PEJM5_C114218.pdf)
C8 | C_0603_1608Metric | 1 | CT41G-0603-2X1-50V-0.01μF-K(N) (https://www.lcsc.com/product-detail/Multilayer-Ceramic-Capacitors-MLCC-SMD-SMT_TORCH-CT41G-0603-2X1-50V-0-01-F-K-N_C136131.html)
FAN5,FAN2 | JST_XH_B4B-XH-A_1x04_P2.50mm_Vertical | 2 | 2.54mm-4P ZZ (https://www.lcsc.com/product-detail/Wire-To-Board-Connector_SHOU-HAN-2-54mm-4P-ZZ_C5368777.html)
C24,C15,C23,C13,C12,C11,C19,C4,C2,C5,C22,C1,C27,C29 | C_0603_1608Metric | 14 | CT41G-0603-2X1-50V-0.1μF-K(N) (https://www.lcsc.com/product-detail/Multilayer-Ceramic-Capacitors-MLCC-SMD-SMT_TORCH-CT41G-0603-2X1-50V-0-1-F-K-N_C125205.html)
R14,R13,R12 | R_0603_1608Metric | 3 | RC0603FR-07470RL (https://www.lcsc.com/product-detail/C114669.html?s_z=n_q_t_470%2520ohm%2520resistor%2520)
J1 | JST_GH_SM08B-GHS-TB_1x08-1MP_P1.25mm_Horizontal | 1 | HX 1.25-8P WTDK (https://www.lcsc.com/product-detail/Wire-To-Board-Connector_hanxia-HX-1-25-8P-WTDK_C5343065.html)
Q7,Q5,Q6 | SOT-23 | 3 | SS8050
D27,D28,D29 | D_SMA | 3 | SS14
D18,D24,D19 | SOD323 | 3 | PESD3V3L1BA
Q2,Q3,Q4 | SOT-23 | 3 | BSS138
C3 | C_0603_1608Metric | 1 | C0603X7R225K6R3NT (https://www.lcsc.com/product-detail/Multilayer-Ceramic-Capacitors-MLCC-SMD-SMT_SANYEAR-C0603X7R225K6R3NT_C2891981.html)
JP3 | PinHeader_2x03_P2.54mm_Vertical_SMD | 1 | KH-2.54PH-2X3P-L11.0-SMT (https://www.lcsc.com/product-detail/C19630969.html?s_z=n_q_KH-2.54PH-2X3P-L11.0-SMT)
R15,R1,R35,R34,R3,R16,R6,R2,R5 | R_0603_1608Metric | 9 | TR0603B100RP0525Z (https://www.lcsc.com/product-detail/Chip-Resistor-Surface-Mount_Ever-Ohms-Tech-TR0603B100RP0525Z_C881023.html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)
C30 | C_0603_1608Metric | 1 | CC0603KRX7R9BB103 (https://www.lcsc.com/product-detail/C100042.html?s_z=n_q_t_100n%2520capacitor)
D8 | D_SMA | 1 | SS34
R17,R23,R27 | R_0603_1608Metric | 3 | RT0603FRE07220RL (https://www.lcsc.com/product-detail/Chip-span-style-background-color-ff0-Resistor-span-Surface-Mount_YAGEO-RT0603FRE07220RL_C863672.html)
JS1 | JST_XH_B4B-XH-A_1x04_P2.50mm_Vertical | 1 | WAFER-XH254Z-4AH (https://www.lcsc.com/product-detail/C22751788.html?s_z=n_WAFER-XH254Z-4A)
D11 | SOT-143 | 1 | PRTR5V0U2X
U13 | SOIC-8_3.9x4.9mm_P1.27mm | 1 | AT24CS64-SSHM
R8,R10,R9 | R_0603_1608Metric | 3 | RT0603FRE1310KL (https://www.lcsc.com/product-detail/Chip-span-style-background-color-ff0-Resistor-span-Surface-Mount_YAGEO-RT0603FRE1310KL_C4226066.html)
R50,R51 | 0805 | 2 | 0805W8F0000T5E
J2 | JST_XH_B3B-XH-A_1x03_P2.50mm_Vertical | 1 | BX-XH2.54-3PZZ (https://www.lcsc.com/product-detail/Wire-To-Board-Connector_Bossie-BX-XH2-54-3PZZ_C18077834.html)
C18,C26,C25,C28 | CP_Elec_10x10.5 | 4 | CK470UF35V167RV0143 (https://www.lcsc.com/product-detail/Aluminum-Electrolytic-Capacitors-SMD_KNSCHA-CK470UF35V167RV0143_C5263873.html)
JP1 | PinHeader_2x03_P2.54mm_Vertical_SMD | 1 | KH-2.54PH-2X3P-L11.0-SMT (https://www.lcsc.com/product-detail/C19630969.html?s_z=n_q_KH-2.54PH-2X3P-L11.0-SMT)
R49 | R_0603_1608Metric | 1 | FRC0603F2212TS (https://www.lcsc.com/product-detail/C2960862.html?s_z=n_q_t_22.1k)
BZ1 | Buzzer_12x9.5RM7.6 | 1 | FMB12A05-5V (https://www.lcsc.com/product-detail/Buzzers_FUET-FMB12A05-5V_C417389.html)
U18,U21 | TO-263-5_TabPin3 | 2 | LM2596S-5
FAN6,FAN1 | Molex_KK-254_AE-6410-04A_1x04_P2.54mm_Vertical | 2 | HC-XH2510-4A-M (https://www.lcsc.com/product-detail/C53151727.html?s_z=n_q_22272041)
U9 | TO-263-2 | 1 | LM7809CS2/TR (https://www.lcsc.com/product-detail/Voltage-Regulators-Linear-Low-Drop-Out-LDO-Regulators_HGSEMI-LM7809CS2-TR_C7432234.html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)
LC2,LC1 | JST_XH_B4B-XH-A_1x04_P2.50mm_Vertical | 2 | WAFER-XH254Z-4A (https://www.lcsc.com/product-detail/Wire-To-Board-Connector_Hanbo-Electronic-WAFER-XH254Z-5A_C7432685.html)
L2,L1 | L_Chilisin_BMRx00060630 | 2 | RVT1A471M0607 (https://www.lcsc.com/product-detail/C335982.html?s_z=n_q_t_470uF)
L3 | 1050 | 1 | FCH1050-470M (https://www.lcsc.com/product-detail/C20415550.html?s_z=n_q_FCH1050-470M)
JP2 | PinHeader_2x03_P2.54mm_Vertical_SMD | 1 | KH-2.54PH-2X3P-L11.0-SMT (https://www.lcsc.com/product-detail/C19630969.html?s_z=n_q_KH-2.54PH-2X3P-L11.0-SMT)
U6 | QFN-48-1EP_7x7mm_P0.5mm_EP5.15x5.15mm | 1 | STM32F411CEU6 (https://www.lcsc.com/product-detail/Microcontrollers-MCU-MPU-SOC_STMicroelectronics-STM32F411CEU6_C60420.html)
FAN4,FAN3,J12 | JST_XH_B2B-XH-A_1x02_P2.50mm_Vertical | 3 | 2.54mm-2P ZZ (https://www.lcsc.com/product-detail/Wire-To-Board-Connector_SHOU-HAN-2-54mm-2P-ZZ_C5368775.html)
C10,C14 | C_0603_1608Metric | 2 | CC0603JRNPO9BN150 (https://www.lcsc.com/product-detail/Multilayer-Ceramic-Capacitors-MLCC-SMD-SMT_YAGEO-CC0603JRNPO9BN150_C107037.html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)
SW1 | SW_DIP_SPSTx02_Slide_6.7x6.64mm_W8.61mm_P2.54mm_LowProfile | 1 | SMXS-02K-TP
F1 | FUSE_01550900M | 1 | 01550900M (https://www.lcsc.com/product-detail/C108518.html?s_z=n_FUSE_01550900M)
J3 | BarrelJack_Horizontal | 1 | DC-005D-20A
C16 | C_0805_2012Metric | 1 | CL21B475KAFNNNE (https://www.lcsc.com/product-detail/C98195.html?s_z=n_q_t_100n%2520capacitor)
U19 | TO-263-5_TabPin3 | 1 | LM2596S-12
Q1 | SOT-23 | 1 | IRLML6344 (https://www.lcsc.com/product-detail/MOSFETs_Guangdong-Hottech-IRLML6344_C5364313.html)
U10 | SOT-23-6 | 1 | USBLC6-4SC6
J4 | PinHeader_1x04_P2.54mm_Vertical | 1 | 2.54-1*4 (https://www.lcsc.com/product-detail/Pin-Headers_ZHOURI-2-54-1-4_C5116483.html)
SW2 | SW_SPST_PTS647_Sx50 | 1 | TS110926038 (https://www.lcsc.com/product-detail/Tactile-Switches_HanElectricity-TS110926038_C22375347.html)
R48 | R_0603_1608Metric | 1 | FRC0603F1003TS (https://www.lcsc.com/product-detail/C2906980.html?s_z=n_q_t_22.1k)
TB2 | TerminalBlock_Phoenix_MKDS-1,5-2-5.08_1x02_P5.08mm_Horizontal | 1 | WJ500V-5.08-2P (https://www.lcsc.com/product-detail/Screw-Terminal-Blocks_Ningbo-Kangnex-Elec-WJ500V-5-08-2P_C8465.html)
RV2 | JST_XH_B3B-XH-A_1x03_P2.50mm_Vertical | 1 | BX-XH2.54-3PZZ-R (https://www.lcsc.com/product-detail/C22388499.html?s_z=n_BX-XH2.54-3PZZ)
L4 | L_Neosid_SMS-ME3015 | 1 | 10uH/SFEK3015A-100M-HF
C6 | C_0603_1608Metric | 1 | GRM188B31H105KAALD (https://www.lcsc.com/product-detail/Multilayer-Ceramic-Capacitors-MLCC-SMD-SMT_Murata-Electronics-GRM188B31H105KAALD_C913562.html)
Y1 | Crystal_SMD_3225-4Pin_3.2x2.5mm | 1 | SX3B25.000F0810F30 (https://www.lcsc.com/product-detail/Crystals_Shenzhen-SCTF-Elec-SX3B25-000F0810F30_C41369918.html)
J6 | JST_XH_B5B-XH-A_1x05_P2.50mm_Vertical | 1 | B5B-XH-A-M(LF)(SN) (https://www.lcsc.com/product-detail/Wire-To-Board-Connector_JST-B5B-XH-A-M-LF-SN_C495550.html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)
Y2 | Crystal_C38-LF_D3.0mm_L8.0mm_Horizontal | 1 | 3438T-32768HPTLNL (https://www.lcsc.com/product-detail/Crystals_HCI-3438T-32768HPTLNL_C5383143.html)
TB1 | TerminalBlock_Phoenix_MKDS-1,5-2-5.08_1x02_P5.08mm_Horizontal | 1 | WJ500V-5.08-2P (https://www.lcsc.com/product-detail/Screw-Terminal-Blocks_Ningbo-Kangnex-Elec-WJ500V-5-08-2P_C8465.html)
D26 | D_SMC | 1 | S6MC
C31 | C_0805_2012Metric | 1 | 0805X5R226M100NT (https://www.lcsc.com/product-detail/C49326685.html?s_z=n_q_t_100n%2520capacitor)
U7 | Texas_R-PUSON-N14 | 1 | TPD6E05U06RVZ

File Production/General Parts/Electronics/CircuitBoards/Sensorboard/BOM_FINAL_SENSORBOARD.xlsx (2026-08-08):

Designator | Quantity | Designation | Part# | Footprint
J4 | 1 | WS2811 | BX-XH2.54-3PZZ (https://www.lcsc.com/product-detail/Wire-To-Board-Connector_Bossie-BX-XH2-54-3PZZ_C18077834.html) | JST_XH_B3B-XH-A_1x03_P2.50mm_Vertical
POWER_IN1 | 1 | Power_in | B5B-XH-A-M(LF)(SN) (https://www.lcsc.com/product-detail/Wire-To-Board-Connector_JST-B5B-XH-A-M-LF-SN_C495550.html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) | JST_XH_B5B-XH-A_1x05_P2.50mm_Vertical
MQ1 | 1 | ~ | MQ2 | MQ2-MODULE
U12 | 1 | SSP7901P33MR | SSP7901P33MR | SOT-23-3
C22,C23,C13 | 3 | 4.7uF | GRM21BB31E475KA75L (https://www.lcsc.com/product-detail/Multilayer-Ceramic-Capacitors-MLCC-SMD-SMT_Murata-Electronics-GRM21BB31E475KA75L_C576489.html) | C_0805_2012Metric
C25 | 1 | 0.1uF | CC0402KRX7R7BB104 | C_0603_1608Metric
MEMS_SMOKE1 | 1 | MEMS_Smoke | MEMS_Smoke | MEMS_SMOKE
BME1 | 1 | ~ | Bme680 | Bme680
SENSOR_IN1 | 1 | SENSOR_OUT | ----RJ45---- | RJ45_NEW
R19 | 1 | 10k | RT0603FRE1310KL (https://www.lcsc.com/product-detail/Chip-span-style-background-color-ff0-Resistor-span-Surface-Mount_YAGEO-RT0603FRE1310KL_C4226066.html) | R_0603_1608Metric
R22 | 1 | 4.3k | 0603WAF4301T5E (https://www.lcsc.com/product-detail/Chip-Resistor-Surface-Mount_UNI-ROYAL-Uniroyal-Elec-0603WAF4301T5E_C23159.html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) | R_0603_1608Metric
ELECBEE1 | 1 | Elec_Smoke | B5B-XH-A-M(LF)(SN) (https://www.lcsc.com/product-detail/Wire-To-Board-Connector_JST-B5B-XH-A-M-LF-SN_C495550.html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) | JST_XH_B5B-XH-A_1x05_P2.50mm_Vertical
OPTICAL_SMOKE1 | 1 | ~ | SM05B-SRSS-TB(LF)(SN) (https://www.lcsc.com/product-detail/Wire-To-Board-Connector_JST-SM05B-SRSS-TB-LF-SN_C136657.html) | JST_SHL_SM05B-SHLS-TF_1x05-1MP_P1.00mm_Horizontal
U6 | 1 | LM317_SOT-223 | LM317 (https://www.lcsc.com/product-detail/Voltage-Regulators-Linear-Low-Drop-Out-LDO-Regulators_HXY-MOSFET-LM317_C7543014.html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) | SOT-223-3_TabPin2
R23,R24 | 2 | 10K | RT0603FRE1310KL (https://www.lcsc.com/product-detail/Chip-span-style-background-color-ff0-Resistor-span-Surface-Mount_YAGEO-RT0603FRE1310KL_C4226066.html) | R_0603_1608Metric
R18 | 1 | 5k | RTT035001FTP (https://www.lcsc.com/product-detail/Chip-Resistor-Surface-Mount_RALEC-RTT035001FTP_C166926.html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) | R_0603_1608Metric
R21 | 1 | 2.2k | FRC0603J222 TS (https://www.lcsc.com/product-detail/Chip-Resistor-Surface-Mount_FOJAN-FRC0603J222-TS_C2907117.html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) | R_0603_1608Metric

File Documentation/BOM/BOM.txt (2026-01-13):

Google Sheet Link: https://docs.google.com/spreadsheets/d/1zxFBzsFjeg29lGvyA2hwyYCAKZ0MYmlyk_qqRtMol1E/edit?usp=sharing

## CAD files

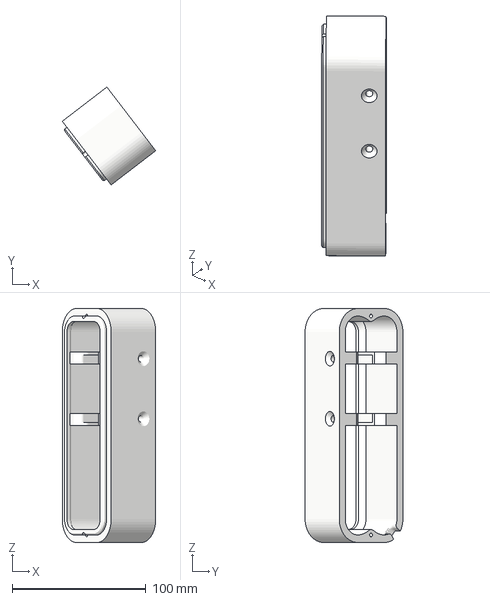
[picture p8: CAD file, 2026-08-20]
3D Printable Files/Size Agnostic/Sensors Assembly/1x_Main_body.3mf
69.8 x 73.2 x 175.0 mm

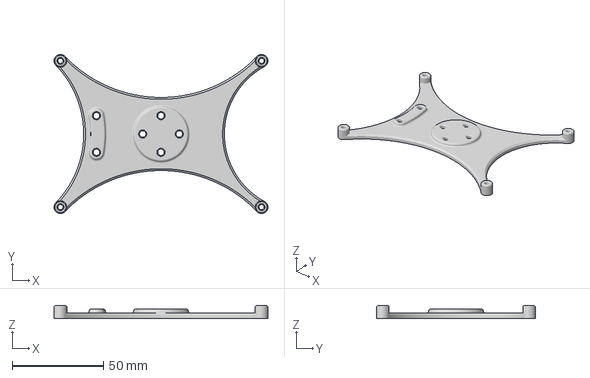
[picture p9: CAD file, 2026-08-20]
3D Printable Files/Size Agnostic/Electronics/1x_Mainboard_Mount.3mf
117.0 x 87.0 x 6.95 mm

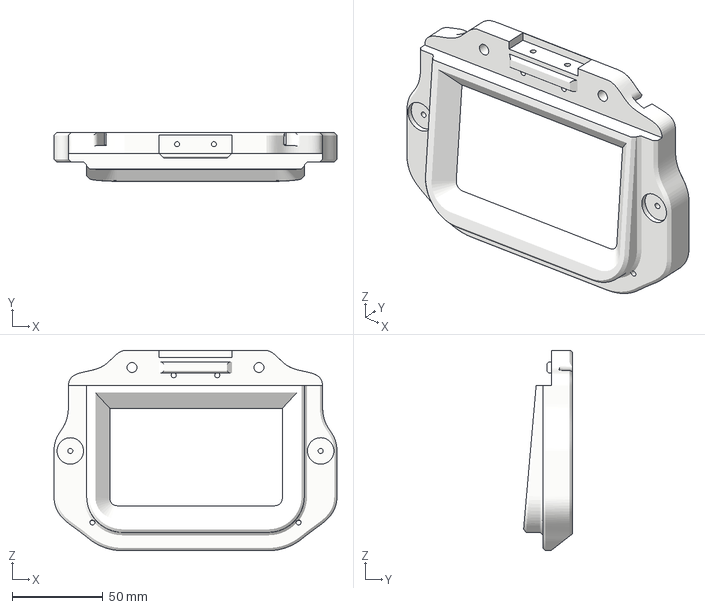
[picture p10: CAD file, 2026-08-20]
3D Printable Files/Size Agnostic/Screen Assembly/1x_Main_body_screen.3mf
156.0 x 26.9 x 110.5 mm

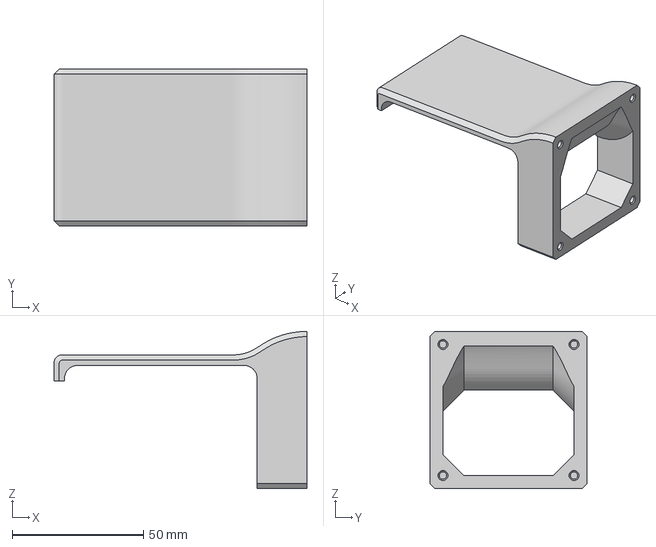
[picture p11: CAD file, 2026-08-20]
3D Printable Files/Printer_Dependent/A1mini_Electronics_Cooling.3mf
96.5 x 60.0 x 60.0 mm

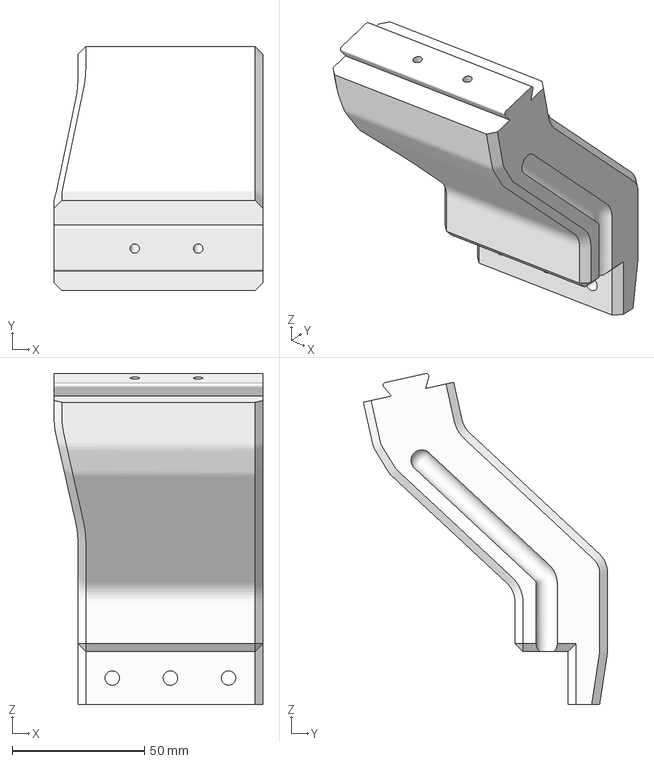
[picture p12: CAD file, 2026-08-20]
3D Printable Files/Size Agnostic/AMS Holder/1x_AMS_Bottom.3mf
79.0 x 92.4 x 125.2 mm

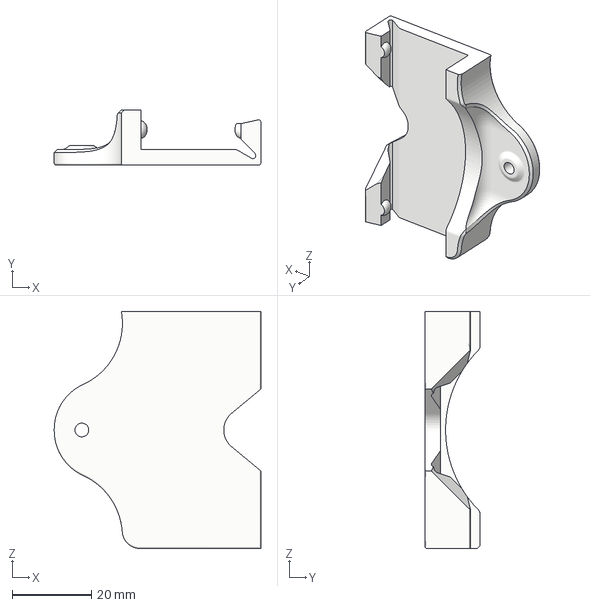
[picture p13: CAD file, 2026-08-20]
3D Printable Files/Size Agnostic/Electronics/1x_6025_Holder.3mf
52.3 x 14.0 x 60.0 mm

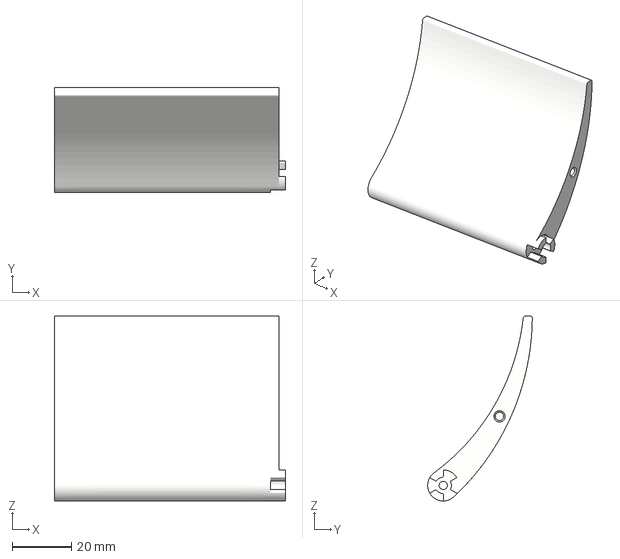
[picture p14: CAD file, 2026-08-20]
3D Printable Files/Size Agnostic/Filtration Assembly/1x_Flap.3mf
77.8 x 35.2 x 62.3 mm

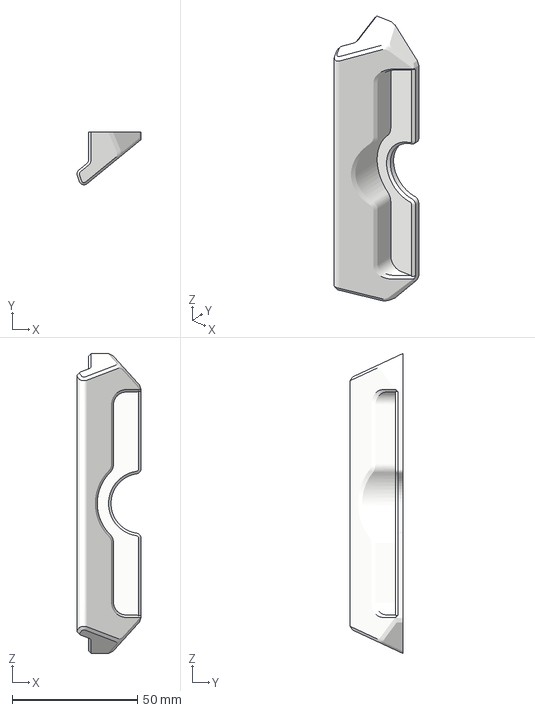
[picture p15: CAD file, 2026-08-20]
3D Printable Files/Size Agnostic/Handles/Front & Back Handles/1x_Handle_Lock.3mf
25.6 x 21.1 x 120.0 mm

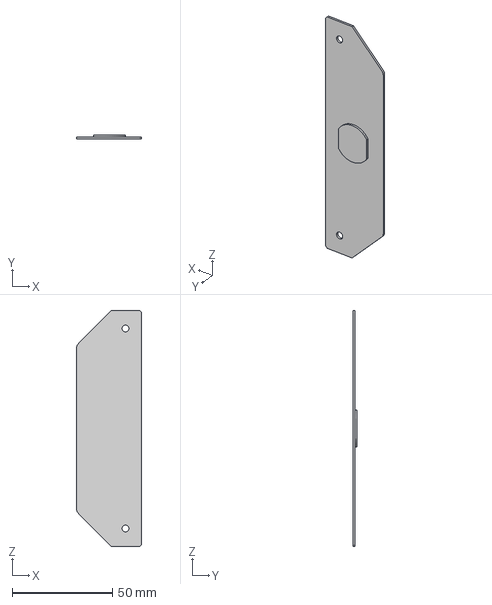
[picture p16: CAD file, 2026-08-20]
3D Printable Files/Size Agnostic/Handles/Front & Back Handles/Metal Handles/2x_Back_Plate_Metal_Handles.3mf
32.5 x 2.00 x 118.0 mm

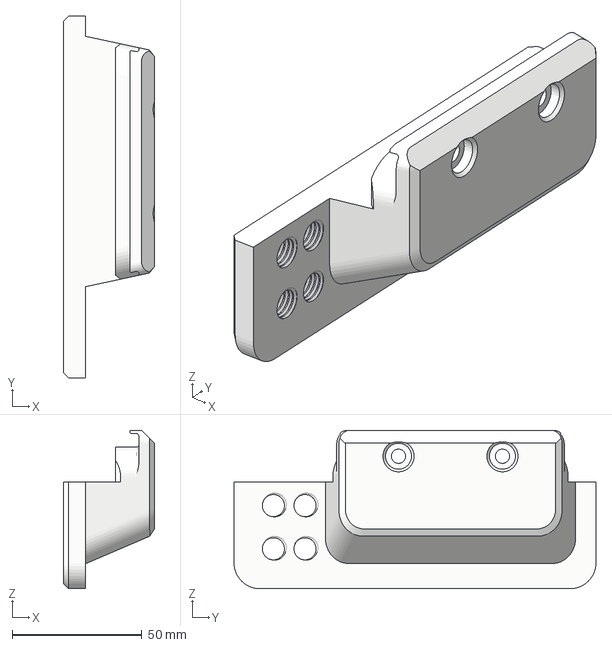
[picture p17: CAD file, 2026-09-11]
3D Printable Files/Size Agnostic/Handles/Side Handles/1x_Handle_L_PTFE.3mf
35.0 x 139.3 x 61.0 mm

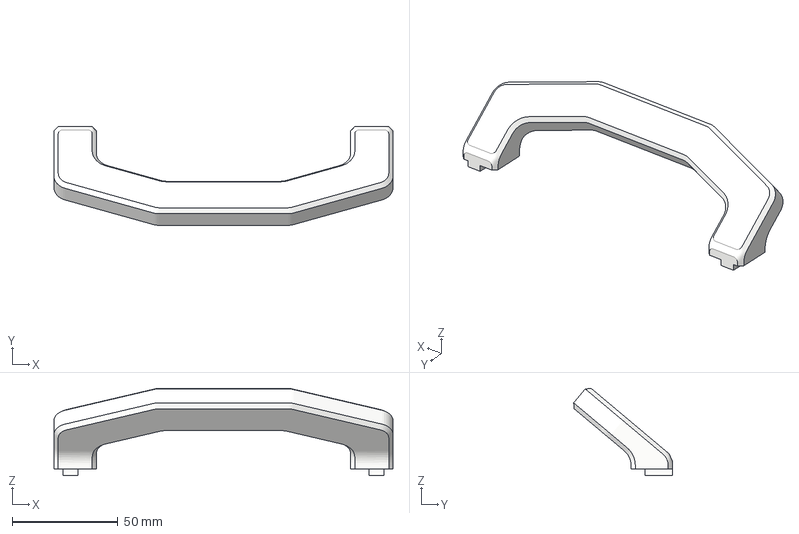
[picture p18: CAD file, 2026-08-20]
3D Printable Files/Size Agnostic/Handles/Top Handle/1x_Top_Handle_A.3mf
160.0 x 46.6 x 41.1 mm

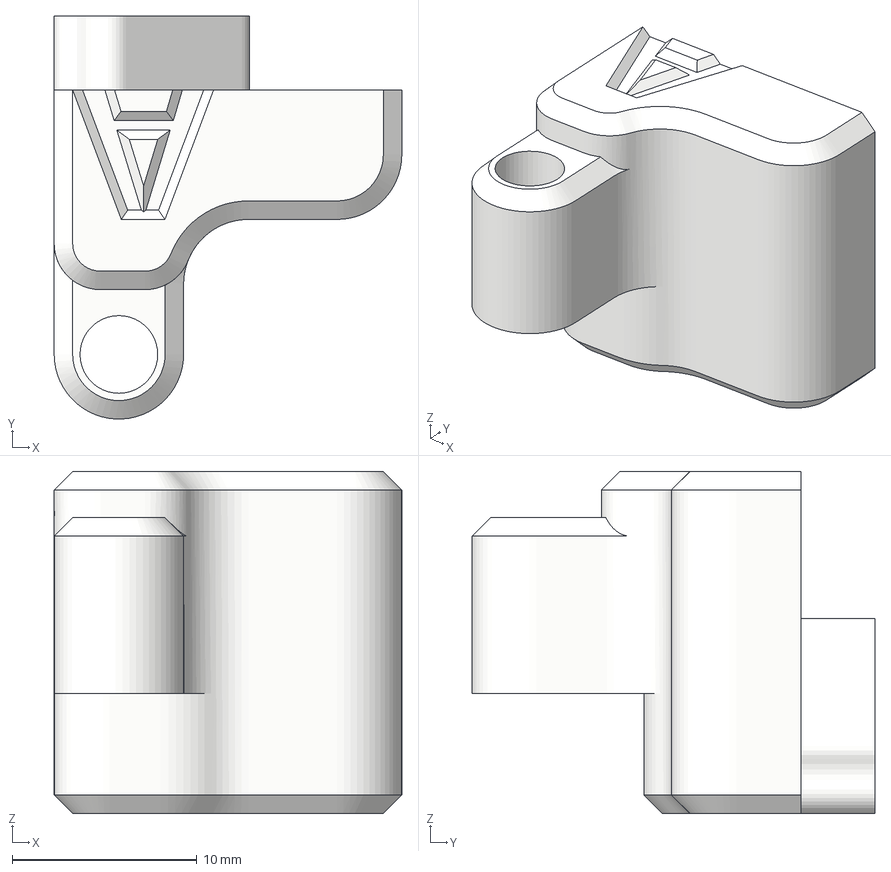
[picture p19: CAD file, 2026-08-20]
3D Printable Files/Size Agnostic/Hinges/Front Hinges/2x_Hinge_A.3mf
18.8 x 21.8 x 18.5 mm

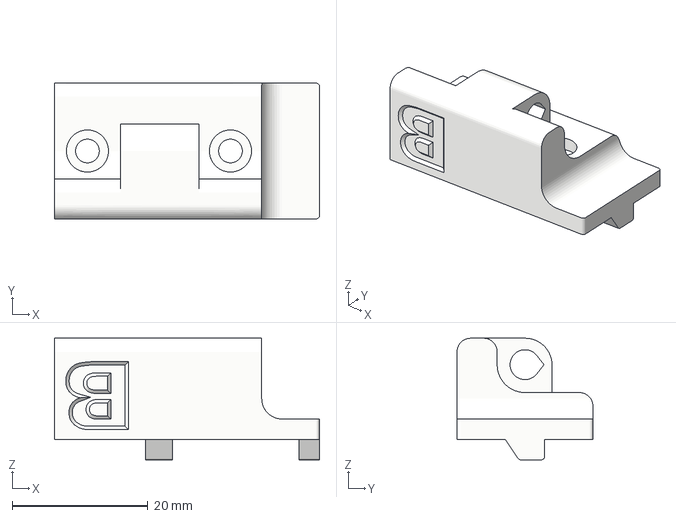
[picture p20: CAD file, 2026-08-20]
3D Printable Files/Size Agnostic/Hinges/Top Hinges/1x_Bottom_Hinge_B.3mf
39.0 x 20.0 x 17.9 mm

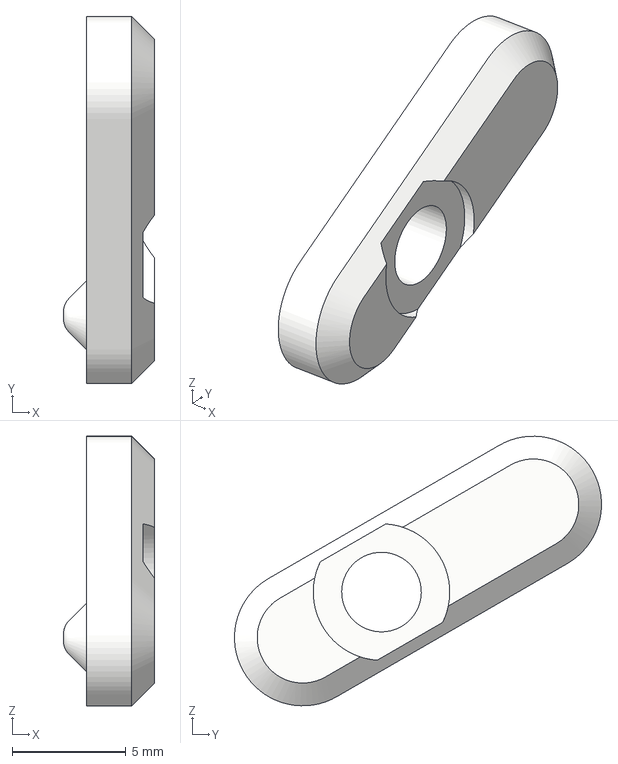
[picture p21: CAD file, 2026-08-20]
3D Printable Files/Size Agnostic/Magnet Holders/Back Panel/4x_Back_Panel_Levers.3mf
4.00 x 16.1 x 11.9 mm

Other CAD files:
PCBs/3d/mainboard.step
3D Printable Files/Size Agnostic/Magnet Holders/Side Panels/1x_Plug_Holder.3mf
3D Printable Files/Size Agnostic/Misc Parts/2x_Electronics_Top_Panel_Holder.3mf
3D Printable Files/Size Agnostic/Screen Assembly/1x_Back_panel_screen.3mf
3D Printable Files/Printer_Dependent/A1_Electronics_Cooling.3mf
3D Printable Files/Size Agnostic/AMS Holder/1x_AMS_Top.3mf
3D Printable Files/Size Agnostic/Electronics/2x_Cable_Organizer.3mf
3D Printable Files/Size Agnostic/Filtration Assembly/1x_Duct_L.3mf
3D Printable Files/Size Agnostic/Filtration Assembly/1x_Duct_R.3mf
3D Printable Files/Size Agnostic/Filtration Assembly/1x_Fan_Holder.3mf
3D Printable Files/Size Agnostic/Filtration Assembly/1x_Filter_Holder.3mf
3D Printable Files/Size Agnostic/Filtration Assembly/1x_FrontSide_Duct.3mf
3D Printable Files/Size Agnostic/Filtration Assembly/1x_Front_Grill_Filter.3mf
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

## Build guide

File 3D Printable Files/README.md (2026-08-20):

# 3D Printable Files

> [!WARNING]
> **Printing is not recommended yet.** These files are ready to review, but small
> improvements may still land before delivery. Please hold off on printing until this note
> is removed, to avoid reprinting a part that changes.

The parts you print yourself, as `.3mf`.

> **Not sure which files you need?**
> [CluraDocs has a picker](https://docs.clura.dev/the-build/preparations/printed-parts):
> choose your size and options and it lists exactly which files to print, how many of each,
> with a preview and a download link per part.

## Print settings

These work for every part except one:

| Setting | Value |
| --- | --- |
| Material | PETG |
| Layer height | 0.2 mm |
| Perimeters | 4 |
| Infill | 20% |

`1x_ServoHead_0.1mm` is the exception and needs a **0.1 mm layer height**. It is a small
splined part that grips the servo shaft, and at 0.2 mm the splines come out too coarse to
engage properly.

Supports are only needed on a few parts.

PLA is acceptable for most parts if that is what you have, with one exception: do not use it
for the lighting fixtures, which sit close to the LEDs and run warmer than the rest of the
build.

## Folder layout

```
Printer_Dependent/     electronics cooling, Bambu A1 and A1 mini only
Size Agnostic/         the same on every enclosure size
  AMS Holder             optional
  Electronics            mainboard mount, fan holder, cable organisers
  Filtration Assembly    one assembly per set of files, see below
  Handles                side, front and back, top
  Hinges                 front and top
  Magnet Holders         back panel and side panels
  Misc Parts
  Screen Assembly
  Sensors Assembly
  Spool Holders          weight sensing (Pro) or plain (Base)
Size Specific/
  PE1/  BE1/  ME1/      acrylic guides, bed cable passage, cable management,
                        jigs, lighting
```

## Quantities

The number at the start of a filename is how many to print for **one enclosure**, so
`2x_Cable_Organizer` means two.

A few depend on your build:

**Filtration assembly.** The files make one assembly. ME1 needs one, PE1 and BE1 need two, so
every quantity in that folder doubles on those sizes: a `2x_` becomes 4.

**Spool holders.** Pro uses the weight-sensing set, which carries the load cells. Base uses
the plain holders. PE1 and BE1 print both a left and a right, ME1 only has room for the
right.

**Front handles.** Without the lock addon print 4 of `3or4X_Handle_NoLock`. With the lock
print 3, plus `1x_Handle_Lock` and `1x_LockStopper`.

**Side handles.** Six files, three left and three right. Print one of each: plain, with a
hole, or with a PTFE passthrough for feeding filament in from outside.

**Magnet mounts.** Two mutually exclusive options. Either the reinforced pair, one left and
one right, or two of `2x_Magnet_Mount_Side_panels`. Do not print both sets.

**Top lighting.** The `Lighting/OPTIONAL` folder is an extra light bar on PE1 and BE1. ME1
does not have the variant.

**Printer dependent.** The electronics cooling ducts only apply to the Bambu Lab A1 and A1
mini. Skip the folder on any other printer.

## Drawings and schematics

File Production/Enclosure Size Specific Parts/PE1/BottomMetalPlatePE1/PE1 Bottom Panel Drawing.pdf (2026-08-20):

514 8 1.5

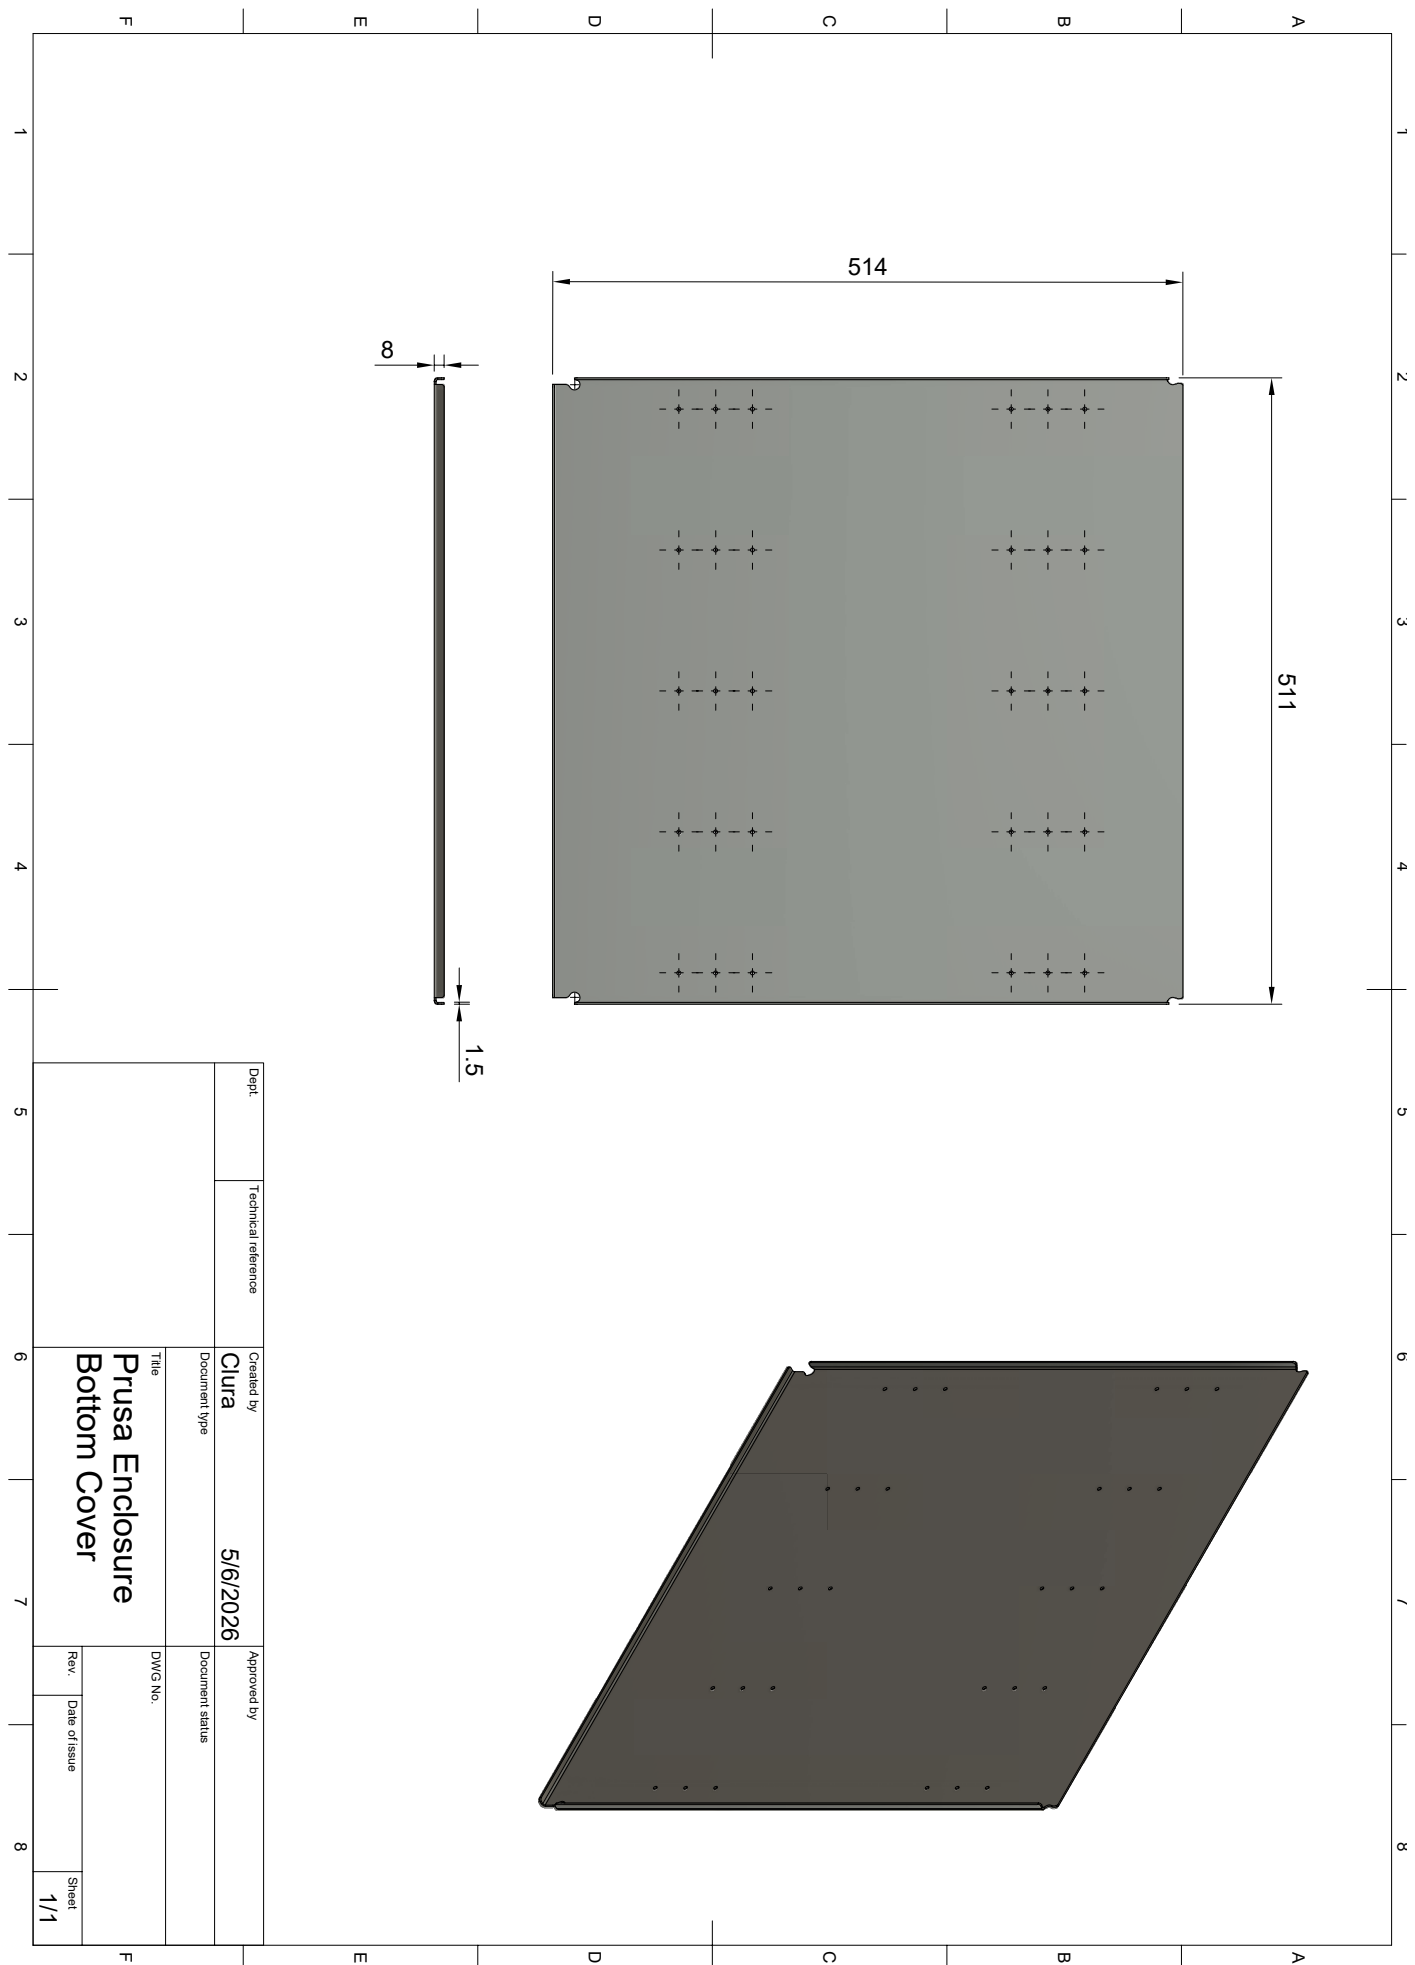
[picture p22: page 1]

1 A 2 3 4 5 6 7 8 1 2 3 4 5 6 7 8 FEDCB FEDCBA Dept. Technical reference Created by Approved by Title DWG No. Document type Document status Rev. Date of issue Sheet 5/6/2026 1/1 Bottom Cover Prusa Enclosure Clura 511

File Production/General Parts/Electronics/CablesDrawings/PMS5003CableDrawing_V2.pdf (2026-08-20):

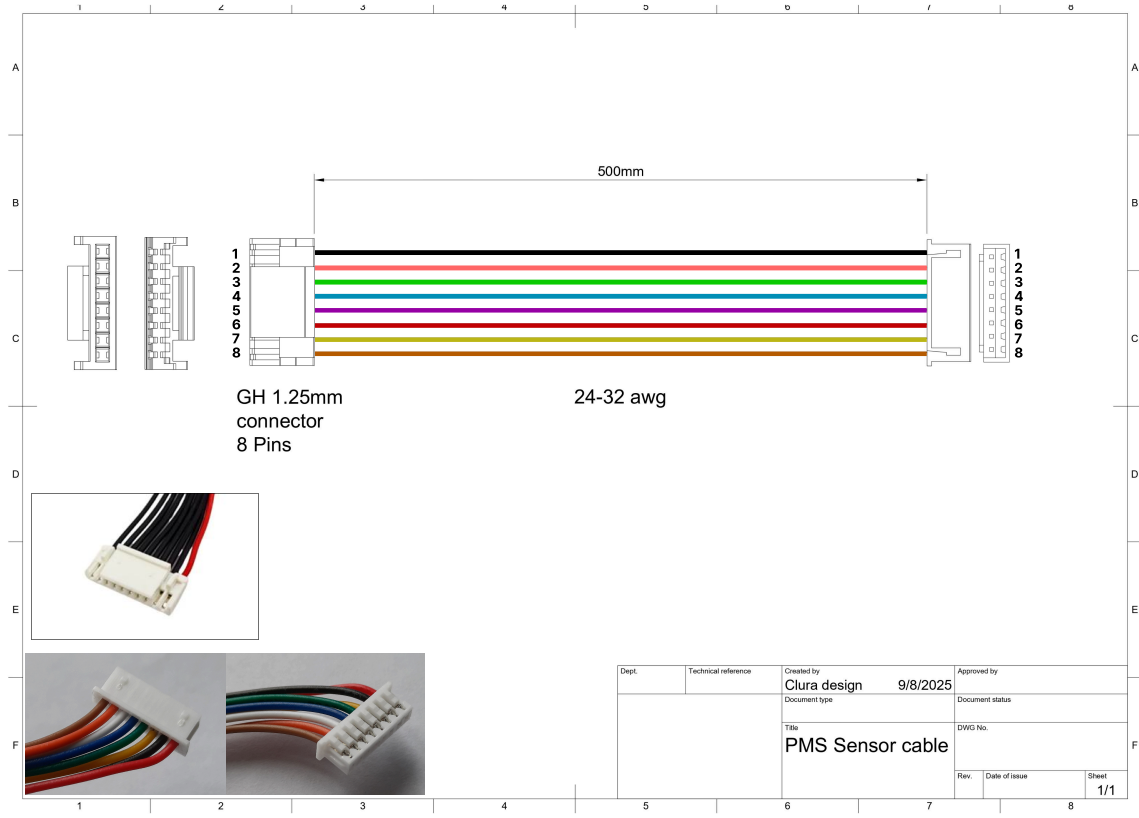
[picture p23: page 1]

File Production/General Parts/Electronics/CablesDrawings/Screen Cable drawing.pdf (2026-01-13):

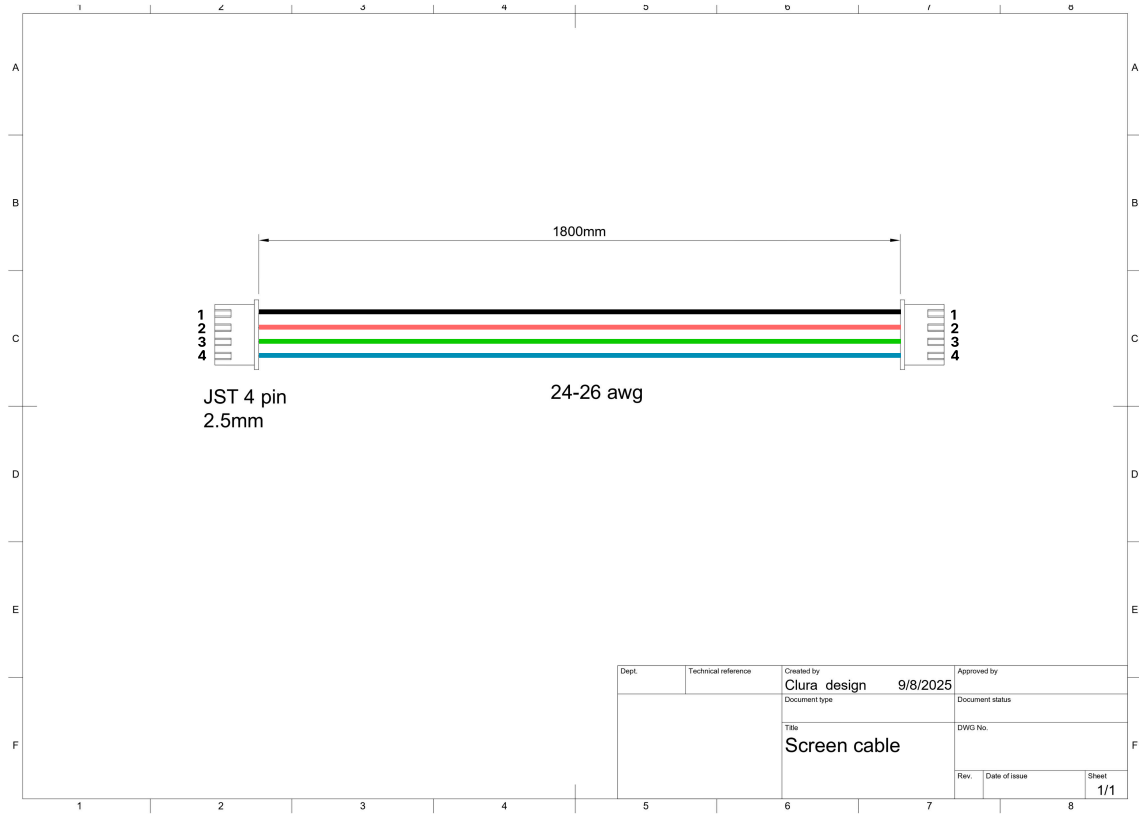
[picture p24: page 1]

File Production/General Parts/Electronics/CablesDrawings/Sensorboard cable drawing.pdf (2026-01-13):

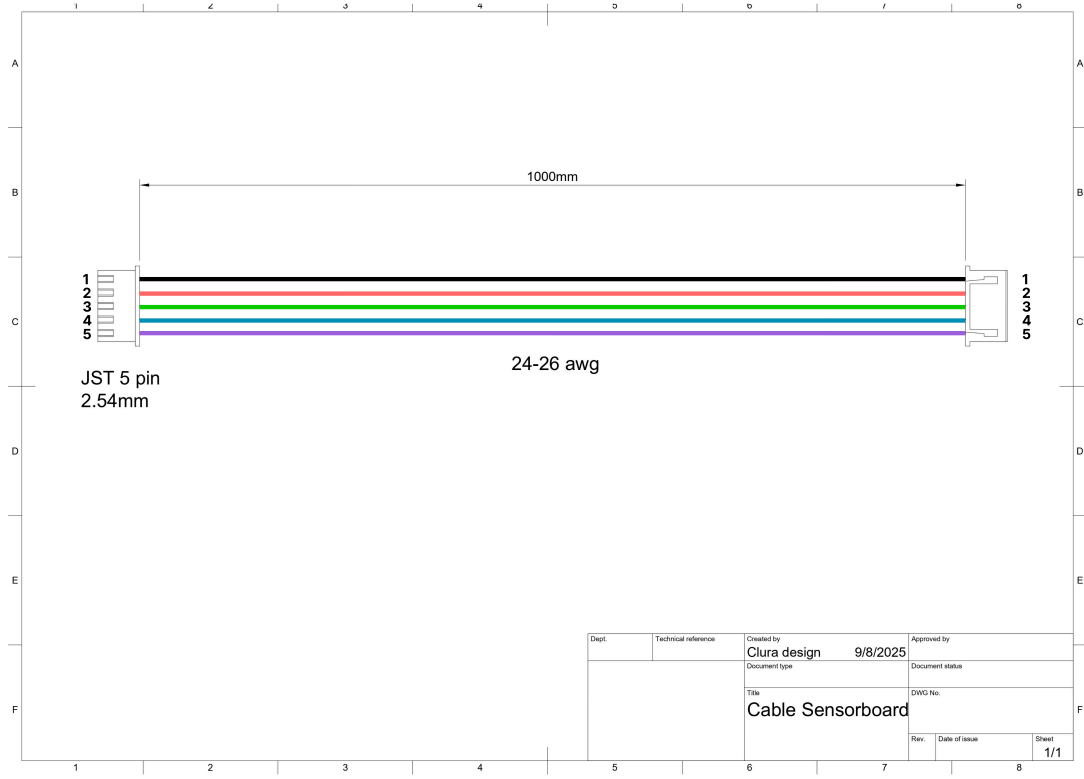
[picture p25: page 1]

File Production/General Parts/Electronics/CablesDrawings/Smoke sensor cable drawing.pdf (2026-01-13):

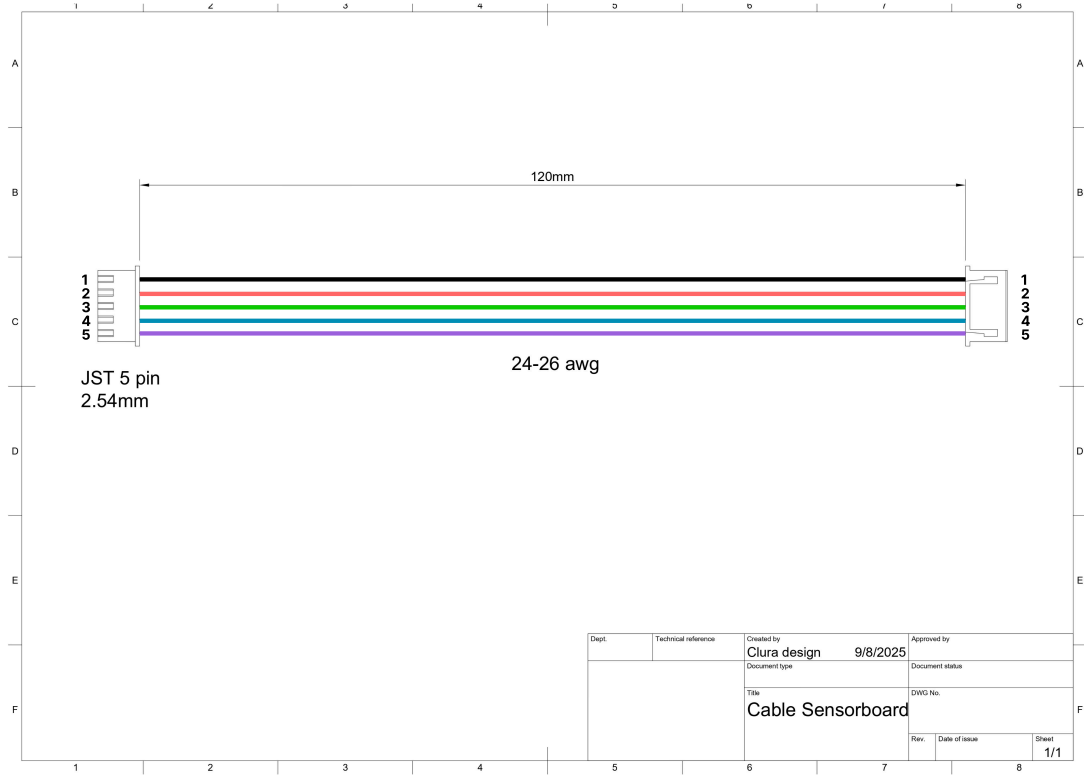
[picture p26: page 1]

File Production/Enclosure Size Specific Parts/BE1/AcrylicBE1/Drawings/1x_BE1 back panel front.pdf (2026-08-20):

560

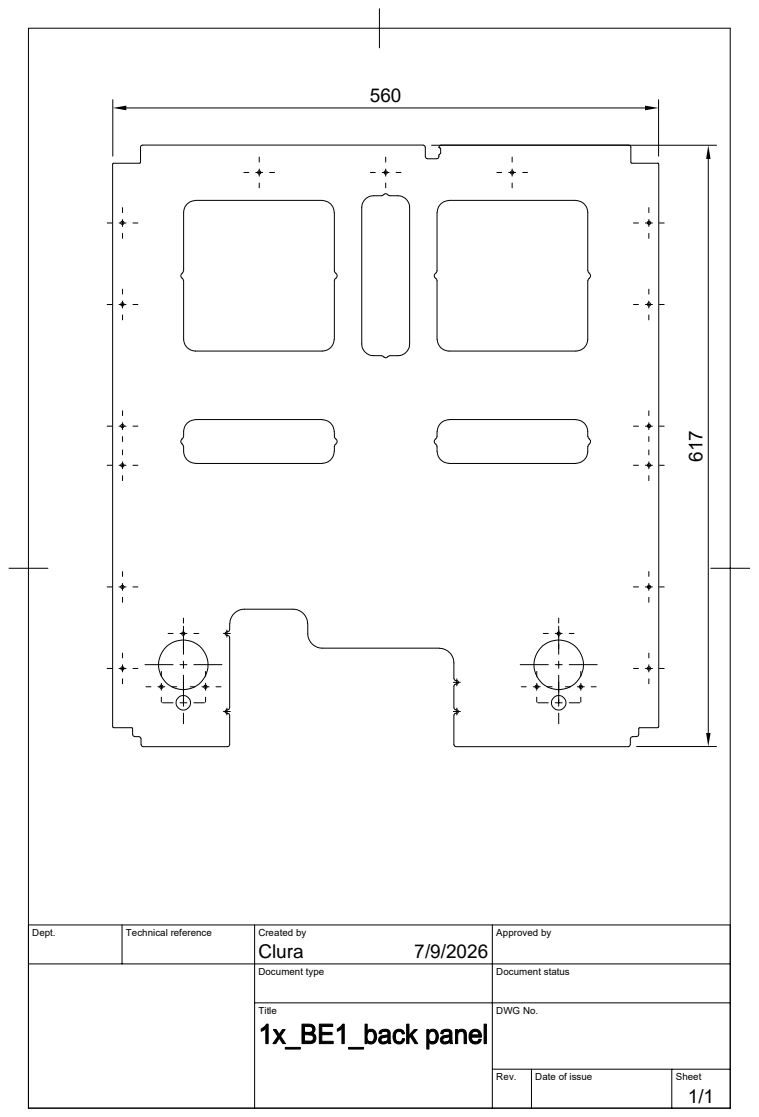
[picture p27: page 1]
Dept.; Technical reference; Created by; Approved by; Document type; Document status; Title; DWG No.; Rev.; Date of issue; Sheet; 1/1⁶¹⁷; Clura

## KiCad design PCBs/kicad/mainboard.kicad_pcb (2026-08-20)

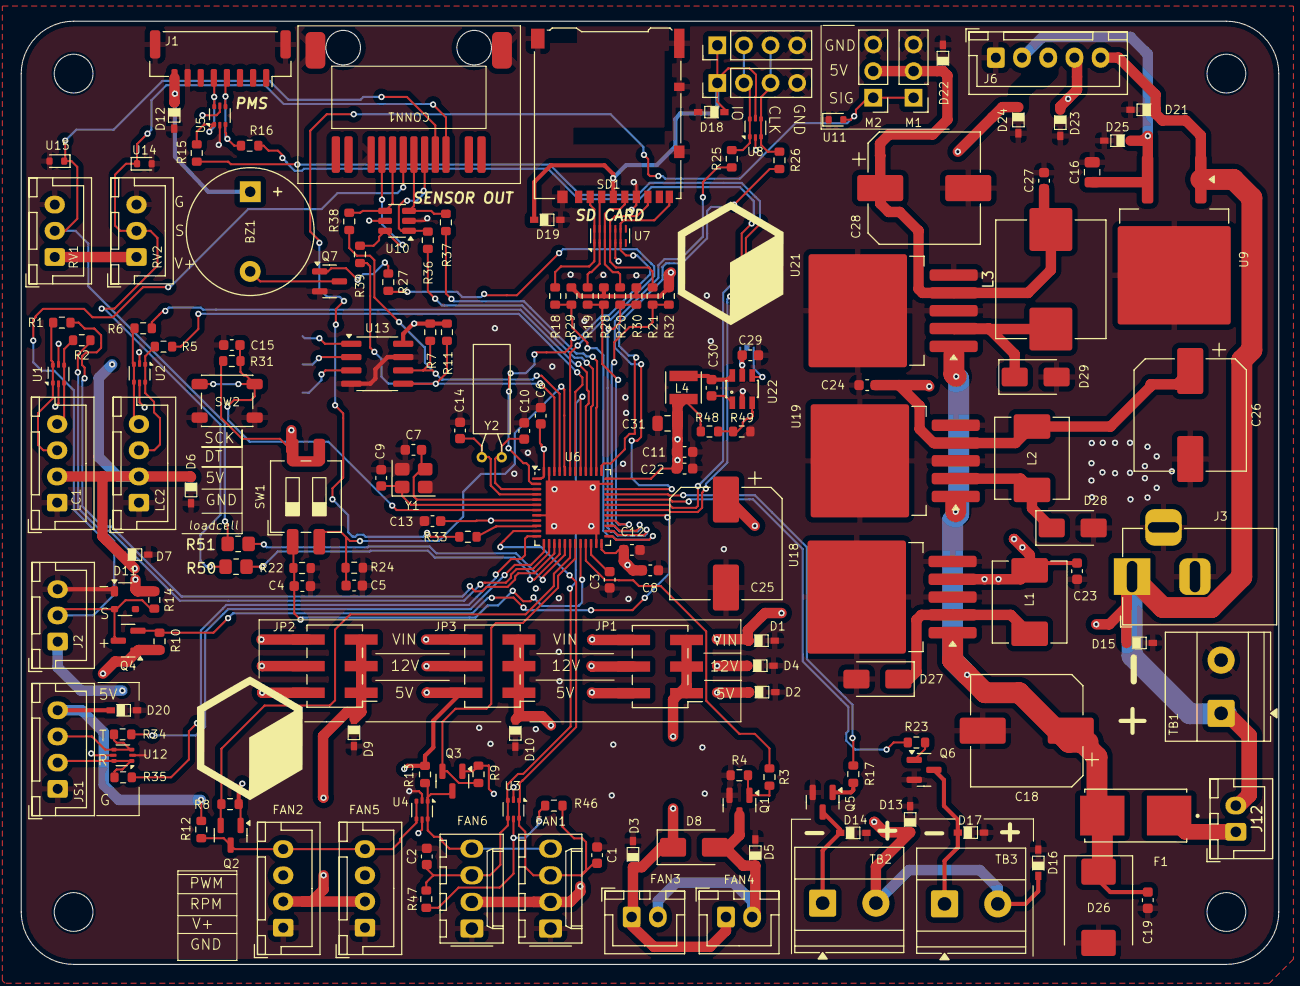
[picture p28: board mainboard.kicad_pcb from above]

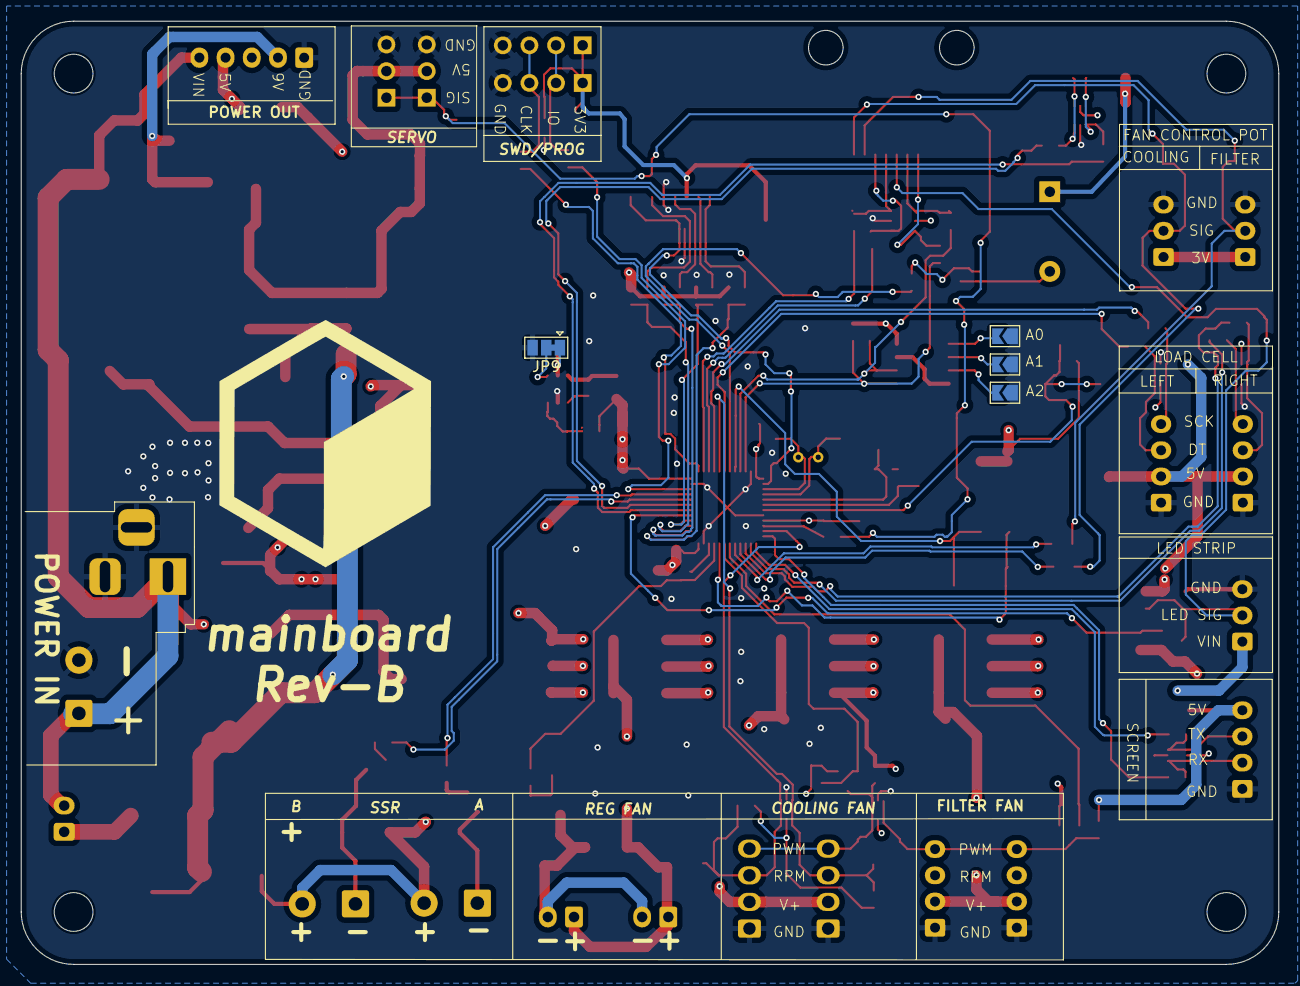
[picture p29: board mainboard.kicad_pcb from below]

Board: 4 copper layers, 120.0 x 90.0 mm, 174 parts (4 on the bottom side), 94 nets.

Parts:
BZ1: Buzzer; Buzzer_12x9.5RM7.6
C1, C2, C4, C5, C11, C12, C13, C15, C22, C23, C24, C27: 0.1uF; C_0603_1608Metric
C3: 2.2uF; C_0603_1608Metric
C6: 1uF; C_0603_1608Metric
C7, C9: 6pF; C_0603_1608Metric
C8: 10nF; C_0603_1608Metric
C10, C14: 15pF; C_0603_1608Metric
C16: 4.7uF; C_0805_2012Metric
C18: 4.7uF; CP_Elec_10x10.5
C19: 4.7uF; C_0603_1608Metric
C25, C26, C28: 470uF; CP_Elec_10x10.5
C29: 100n; C_0603_1608Metric
C30: 10n; C_0603_1608Metric
C31: 22u; C_0805_2012Metric
CONN1: RJ45_NEW
D1, D3, D5, D9, D10, D15, D21: BSD3A311V; SOD323
D2, D6, D7, D12, D13, D14, D16, D17, D20, D22, D23: PESD5V0S1UA; SOD323
D4, D25: PESD12VS1UA.; SOD323
D8: SS34; D_SMA
D11: PRTR5V0U2X; SOT-143
D18, D19, D24: PESD3V3L1BA; SOD323
D26: S6MC; D_SMC
D27, D28, D29: SS14; D_SMA
F1: 3A; FUSE_01550900M
FAN1, FAN6: 140mm_FAN; Molex_KK-254_AE-6410-04A_1x04_P2.54mm_Vertical
FAN2, FAN5: 60mm_FAN; JST_XH_B4B-XH-A_1x04_P2.50mm_Vertical
FAN3, FAN4: Fan; JST_XH_B2B-XH-A_1x02_P2.50mm_Vertical
H1, H2, H3, H4: MountingHole; MountingHole_3.7mm
J1: pms5003; JST_GH_SM08B-GHS-TB_1x08-1MP_P1.25mm_Horizontal
J2: LED Strip; JST_XH_B3B-XH-A_1x03_P2.50mm_Vertical
J3: POWER IN TERMINAL; BarrelJack_Horizontal
J4, J5: SWD HEADER; PinHeader_1x04_P2.54mm_Vertical
J6: Power_Out; JST_XH_B5B-XH-A_1x05_P2.50mm_Vertical
J12: SWITCH; JST_XH_B2B-XH-A_1x02_P2.50mm_Vertical
JP1: REG FAN JUMPER; PinHeader_2x03_P2.54mm_Vertical_SMD
JP2: 60MM FAN JUMPER; PinHeader_2x03_P2.54mm_Vertical_SMD
JP3: 140 MM FAN JUMPER; PinHeader_2x03_P2.54mm_Vertical_SMD
JP4, JP5, JP6: SolderJumper_2_Open; SolderJumper-2_P1.3mm_Open_TrianglePad1.0x1.5mm
JP9: JMP; SolderJumper-3_P1.3mm_Bridged12_Pad1.0x1.5mm
JS1: Screen; JST_XH_B4B-XH-A_1x04_P2.50mm_Vertical
L1, L2: 47uH; L_Chilisin_BMRx00060630
L3: 47uH; L_APV_APH1050
L4: 10uH/SFEK3015A-100M-HF; L_Neosid_SMS-ME3015
LC1, LC2: LOAD CELL AMP; JST_XH_B4B-XH-A_1x04_P2.50mm_Vertical
M1, M2: Motor_Servo; PinHeader_1x03_P2.54mm_Vertical
Q1: MOSFET-FAN; SOT-23
Q2, Q3, Q4: BSS138; SOT-23
Q5, Q6, Q7: SS8050; SOT-23
R1, R2, R3, R5, R6, R15, R16, R34, R35: 100R; R_0603_1608Metric
R4, R7, R11, R22, R24, R28, R29, R30, R31, R32, R46, R47: 10K; R_0603_1608Metric
R8, R9, R10: 10k; R_0603_1608Metric
R12, R13, R14: 470R; R_0603_1608Metric
R17, R23, R27: 220R; R_0603_1608Metric
R18, R19, R20, R21, R25, R26, R33, R36, R37, R38, R39: 22R; R_0603_1608Metric
R48: 100k; R_0603_1608Metric
R49: 22.1k; R_0603_1608Metric
R50, R51: 0R; R_0805_2012Metric_Pad1.20x1.40mm_HandSolder
RV1: F60; JST_XH_B3B-XH-A_1x03_P2.50mm_Vertical
RV2: F140; JST_XH_B3B-XH-A_1x03_P2.50mm_Vertical
SD1: Micro_SD_Card_Det1; microSD_HC_Hirose_DM3AT-SF-PEJM5
SW1: BOOT_JP; SW_DIP_SPSTx02_Slide_6.7x6.64mm_W8.61mm_P2.54mm_LowProfile
SW2: RESET_SW; SW_SPST_PTS647_Sx50
TB1: POWER; TerminalBlock_Phoenix_MKDS-1,5-2-5.08_1x02_P5.08mm_Horizont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
TB2: 5V SSR TERMINAL1; TerminalBlock_Phoenix_MKDS-1,5-2-5.08_1x02_P5.08mm_Horizont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
TB3: 5V SSR TERMINAL2; TerminalBlock_Phoenix_MKDS-1,5-2-5.08_1x02_P5.08mm_Horizont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
U1, U2, U3, U4, U5, U8, U12: USBLC6-2P6; SOT-666
U6: STM32F411CEUx; QFN-48-1EP_7x7mm_P0.5mm_EP5.15x5.15mm
U7: TPD6E05U06RVZ; Texas_R-PUSON-N14
U9: L7809; TO-263-2
U10: USBLC6-4SC6; SOT-23-6
U11, U14, U15: BNTPD1E05U06DYAR; D_SOD-523
U13: AT24CS64-SSHM; SOIC-8_3.9x4.9mm_P1.27mm
U18, U21: LM2596S-5; TO-263-5_TabPin3
U19: LM2596S-12; TO-263-5_TabPin3
U22: SY8120B; SOT23-6
Y1: 25MHz; Crystal_SMD_3225-4Pin_3.2x2.5mm
Y2: 32.768KHz; Crystal_C38-LF_D3.0mm_L8.0mm_Horizontal

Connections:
+3.3V: C6.1, C8.1, C11.1, C12.1, C13.1, C22.1, C31.1, D18.1, D19.1, D24.1, J4.1, J5.1, L4.2, Q2.1 (G), Q3.1 (G), Q4.1 (G), R7.1, R8.1, R9.1, R10.1, R11.1, R28.1, R29.1, R30.1, R31.1, R32.1, R46.1, R47.1, R48.1, RV1.1, RV2.1, SD1.4 (VDD), SW1.3, SW1.4, U1.5 (VBUS), U2.5 (VBUS), U3.5 (VBUS), U5.5 (VBUS), U6.1 (VBAT), U6.9 (VDDA), U6.24 (VDD), U6.36 (VDD), U6.48 (VDD), U8.5 (VBUS), U10.5 (VBUS), U12.5 (VBUS), U13.8 (VCC)
+5V: BZ1.1 (+), C23.1, C25.1, D2.1, D6.1, D7.1, D11.4 (VCC), D12.1, D13.1, D16.1, D20.1, D23.1, J1.8 (VCC), J6.4, JP1.2, JP2.2, JP3.2, JS1.4, L1.2, LC1.2 (VCC), LC2.2 (VCC), R12.1, R13.1, R14.1, TB2.2, TB3.2, U4.5 (VBUS), U18.4 (FB)
+5VSERVO: C27.1, C28.1, D22.1, L3.2, M1.2 (+), M2.2 (+), U21.4 (FB)
+9V: C16.1, D25.1, J6.2, U9.3 (OUT)
+12V: C24.1, C26.1, C29.1, D4.1, JP1.4, JP2.4, JP3.4, JP9.1 (A), L2.2, U19.4 (FB), U22.5 (IN)
/12-24V_IN: D1.1, D15.1, D21.1, J2.1, J3.1, J6.5, J12.2, JP1.6, JP2.6, JP3.6, TB1.1, U9.1 (IN)
/ALARM: R36.2, U6.39 (PB3)
/BOOT0: C5.1, R24.1, SW1.2, U6.44 (BOOT0)
/BOOT1: C4.1, R22.1, SW1.1, U6.20 (PB2)
/BUZZER: R27.2, U6.43 (PB7)
/CLK: R20.1, R30.2, U6.26 (PB13)
/CS: R18.1, R29.2, U6.25 (PB12)
/DET: SD1.9 (DET_B), U6.2 (PC13), U7.6 (NC), U7.9 (D3+)
/F60_HS: FAN2.4 (PWM), FAN5.4 (PWM), Q2.3 (D), R12.2, U4.3 (I/O2), U4.4 (I/O2)
/F60_LS: Q2.2 (S), R8.2, U6.18 (PB0)
/F140_HS: FAN1.4 (PWM), FAN6.4 (PWM), Q3.3 (D), R13.2, U4.1 (I/O1), U4.6 (I/O1)
/F140_LS: Q3.2 (S), R9.2, U6.19 (PB1)
/HX1DT: R1.1, U6.15 (PA5)
/HX1_SCK: R2.1, U6.14 (PA4)
/HX2DT: R5.1, U6.42 (PB6)
/HX2_SCK: R6.1, U6.40 (PB4)
/LED_LOW_SIDE: Q4.2 (S), R10.2, U6.29 (PA8)
/MEMS_AOUT: CONN1.1, R50.2, RV2.2, U14.1 (I/O)
/MISO: R21.1, R32.2, U6.27 (PB14)
/MOSI: R19.1, R28.2, U6.28 (PB15)
/MQ2: CONN1.2, R51.2, RV1.2, U15.1 (I/O)
/MUTE: R37.2, U6.38 (PA15)
/NRST: C15.1, R31.2, SW2.1, U6.7 (NRST)
/PA13: R25.1, U6.34 (PA13)
/PA14: R26.1, U6.37 (PA14)
/PH0: C7.2, U6.5 (PH0), Y1.3
/PH1: C9.2, U6.6 (PH1), Y1.1
/PMS_RX: R15.1, U6.30 (PA9)
/PMS_TX: R16.1, U6.31 (PA10)
/PWM_REG: R3.1, U6.21 (PB10)
/SCL: R7.2, R38.2, U6.45 (PB8), U13.6 (SCL)
/SCREEN_RX: R35.1, U6.12 (PA2)
/SCREEN_TX: R34.1, U6.13 (PA3)
/SDA: R11.2, R39.2, U6.46 (PB9), U13.5 (SDA)
/SERV0: R33.1, U6.10 (PA0)
/SSR1: R17.2, U6.33 (PA12)
/SSR2: R23.2, U6.32 (PA11)
/Sensor Board/GND: C18.2, C19.2
/TACH1: C1.2, FAN1.3 (Tacho), R46.2, U3.1 (I/O1), U3.6 (I/O1), U6.11 (PA1)
/TACH2: C2.1, FAN6.3 (Tacho), R47.2, U3.3 (I/O2), U3.4 (I/O2), U6.41 (PB5)
/WS2811: CONN1.5, D11.2 (I/O1), J2.2, Q4.3 (D), R14.2
/XTAL1A: C10.2, U6.3 (PC14), Y2.1
/XTAL1B: C14.2, U6.4 (PC15), Y2.2
/power/VIN: D26.1 (K), F1.2, U18.1 (VIN), U19.1 (VIN), U21.1 (VIN)
GND: C1.1, C2.2, C3.2, C4.2, C5.2, C6.2, C7.1, C8.2, C9.1, C10.1, C11.2, C12.2, C13.2, C14.1, C15.2, C16.2, C22.2, C23.2, C24.2, C25.2, C26.2, C27.2, C28.2, C29.2, C31.2, CONN1.8, CONN1.SH, D1.2, D2.2, D3.2, D4.2, D5.2, D6.2, D7.2, D9.2, D10.2, D11.1 (GND), D12.2, D13.2, D14.2, D15.2, D16.2, D17.2, D18.2, D19.2, D20.2, D21.2, D22.2, D23.2, D24.2, D25.2, D26.2 (A), D27.2 (A), D28.2 (A), D29.2 (A), FAN1.1 (-), FAN2.1 (-), FAN5.1 (-), FAN6.1 (-), J1.7 (GND), J1.MP, J2.3, J3.2, J3.3, J4.4, J5.4, J6.1, JP4.1 (A), JP5.1 (A), JP6.1 (A), JP9.3 (B), JS1.1, LC1.1 (GND), LC2.1 (GND), M1.3 (-), M2.3 (-), Q1.2 (S), Q5.2 (E), Q6.2 (E), Q7.2 (E), R4.1, R22.2, R24.2, R49.2, RV1.3, RV2.3, SD1.6 (VSS), SD1.10 (DET_A), SD1.11 (SHIELD), SW2.2, TB1.2, U1.2 (GND), U2.2 (GND), U3.2 (GND), U4.2 (GND), U5.2 (GND), U6.8 (VSSA), U6.23 (VSS), U6.35 (VSS), U6.47 (VSS), U6.49 (VSS), U7.5 (GND), U7.10 (GND), U8.2 (GND), U9.2 (GND), U10.2 (GND), U11.1 (I/O), U12.2 (GND), U13.4 (GND), U13.7 (WP), U14.2 (GND), U15.2 (GND), U18.3 (GND), U18.5 (~ON/OFF), U19.3 (GND), U19.5 (~ON/OFF), U21.3 (GND), U21.5 (~ON/OFF), U22.2 (GND), Y1.2, Y1.4
unnamed: BZ1.2 (-), Q7.3 (C)
unnamed: D5.1, D8.2 (A), FAN3.2 (-), FAN4.2 (-), Q1.3 (D)
unnamed: D3.1, D8.1 (K), FAN3.1 (+), FAN4.1 (+), JP1.1, JP1.3, JP1.5
unnamed: D27.1 (K), L1.1, U18.2 (OUT)
unnamed: D28.1 (K), L2.1, U19.2 (OUT)
unnamed: D29.1 (K), L3.1, U21.2 (OUT)
unnamed: D10.1, FAN1.2 (+), FAN6.2 (+), JP3.1, JP3.3, JP3.5
unnamed: D9.1, FAN2.2 (+), FAN5.2 (+), JP2.1, JP2.3, JP2.5
unnamed: J1.5 (RX), R15.2, U5.1 (I/O1), U5.6 (I/O1)
unnamed: J1.4 (TX), R16.2, U5.3 (I/O2), U5.4 (I/O2)
unnamed: J4.2, J5.2, R25.2, U8.1 (I/O1), U8.6 (I/O1)
unnamed: J4.3, J5.3, R26.2, U8.3 (I/O2), U8.4 (I/O2)
unnamed: F1.1, J12.1
unnamed: JP4.2 (B), U13.1 (A0)
unnamed: JP5.2 (B), U13.2 (A1)
unnamed: JP6.2 (B), U13.3 (A2)
unnamed: JP9.2 (C), U22.4 (EN)
unnamed: JS1.2, R35.2, U12.1 (I/O1), U12.6 (I/O1)
unnamed: JS1.3, R34.2, U12.3 (I/O2), U12.4 (I/O2)
unnamed: LC1.3 (DT), R1.2, U1.1 (I/O1), U1.6 (I/O1)
unnamed: LC1.4 (SCK), R2.2, U1.3 (I/O2), U1.4 (I/O2)
unnamed: LC2.3 (DT), R5.2, U2.1 (I/O1), U2.6 (I/O1)
unnamed: LC2.4 (SCK), R6.2, U2.3 (I/O2), U2.4 (I/O2)
unnamed: M1.1 (PWM), M2.1 (PWM), R33.2, U11.2 (GND)
unnamed: Q1.1 (G), R3.2, R4.2
unnamed: Q5.1 (B), R17.1
unnamed: D14.1, Q5.3 (C), TB2.1
unnamed: Q6.1 (B), R23.1
unnamed: D17.1, Q6.3 (C), TB3.1
unnamed: Q7.1 (B), R27.1
unnamed: R20.2, SD1.5 (CLK), U7.3 (NC), U7.12 (D2+)
unnamed: R19.2, SD1.3 (CMD), U7.2 (NC), U7.13 (D1-)
unnamed: R21.2, SD1.7 (DAT0), U7.4 (NC), U7.11 (D2-)
unnamed: R18.2, SD1.2 (DAT3/CD), U7.1 (NC), U7.14 (D1+)
unnamed: R50.1, U6.16 (PA6)
unnamed: R51.1, U6.17 (PA7)
unnamed: C3.1, U6.22 (VCAP1)
unnamed: CONN1.3, R36.1, U10.1 (I/O1)
unnamed: CONN1.4, R37.1, U10.3 (I/O2)
unnamed: CONN1.6, R38.1, U10.4 (I/O3)
unnamed: CONN1.7, R39.1, U10.6 (I/O4)
unnamed: C30.1, U22.1 (BS)
unnamed: R48.2, R49.1, U22.3 (FB)
unnamed: C30.2, L4.1, U22.6 (LX)

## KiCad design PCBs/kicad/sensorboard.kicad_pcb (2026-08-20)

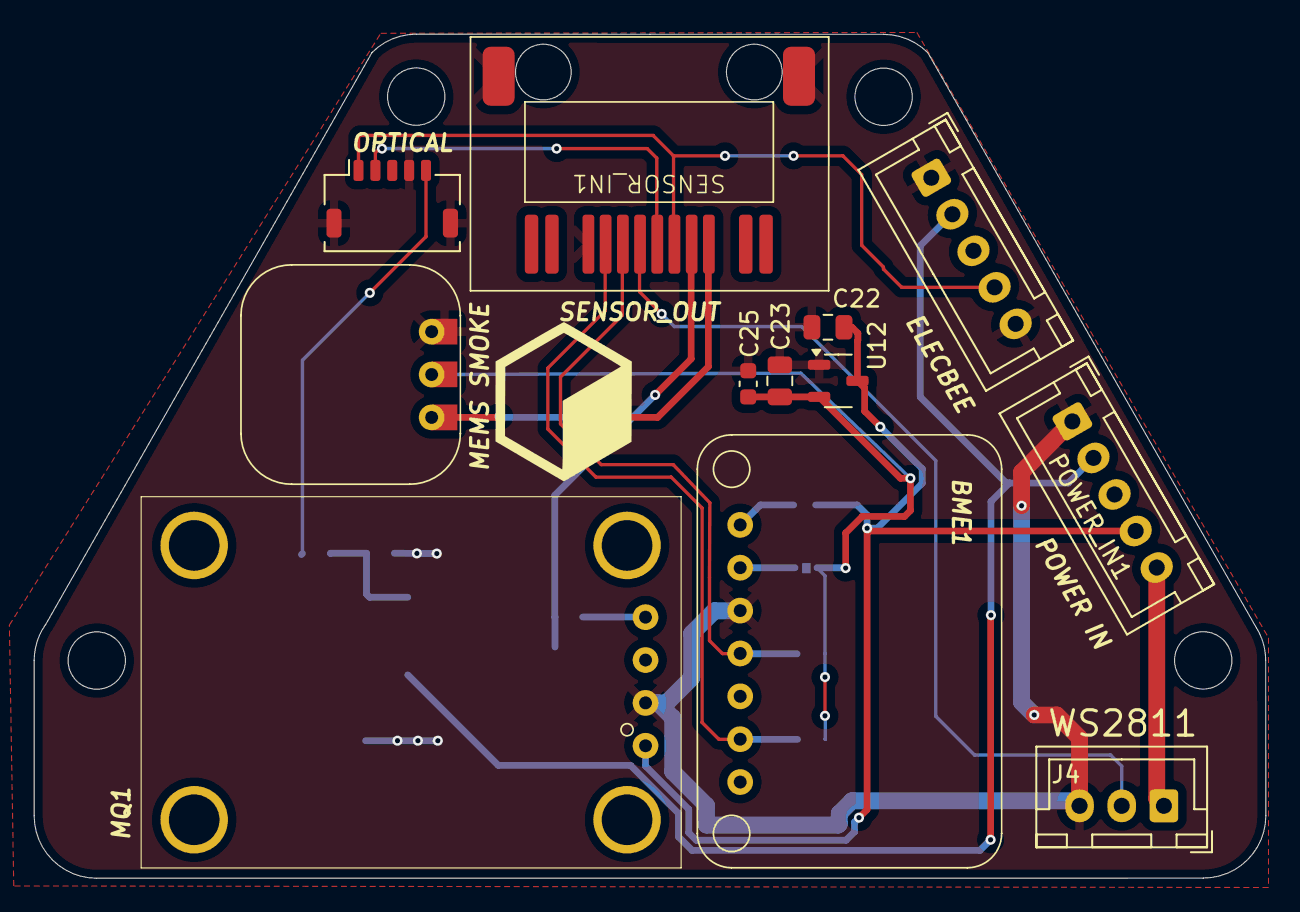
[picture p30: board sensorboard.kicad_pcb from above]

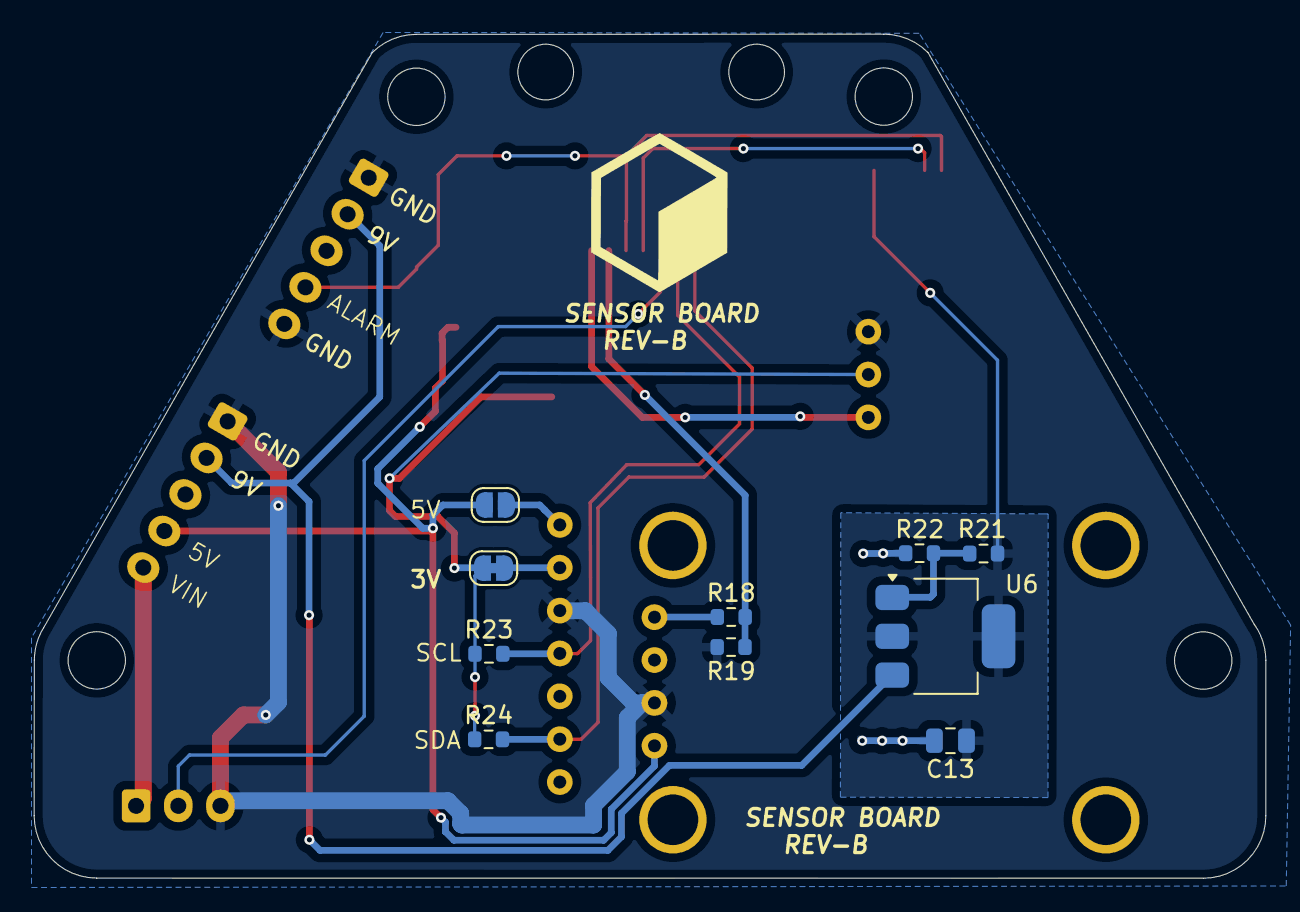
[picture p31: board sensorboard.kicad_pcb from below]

Board: 2 copper layers, 73.0 x 50.0 mm, 22 parts (10 on the bottom side), 17 nets.

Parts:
BME1: Bme680
C13, C22, C23: 4.7uF; C_0805_2012Metric
C25: 0.1uF; C_0603_1608Metric
ELECBEE1: Elec_Smoke; JST_XH_B5B-XH-A_1x05_P2.50mm_Vertical
J4: WS2811; JST_XH_B3B-XH-A_1x03_P2.50mm_Vertical
JP1: Jumper_2_Open; SolderJumper-2_P1.3mm_Open_RoundedPad1.0x1.5mm
JP2: Jumper_2_Bridged; SolderJumper-2_P1.3mm_Bridged_RoundedPad1.0x1.5mm
MEMS_SMOKE1: MEMS_Smoke; MEMS_SMOKE
MQ1: MQ2-MODULE
OPTICAL_SMOKE1: JST_SHL_SM05B-SHLS-TF_1x05-1MP_P1.00mm_Horizontal
POWER_IN1: Power_in; JST_XH_B5B-XH-A_1x05_P2.50mm_Vertical
R18: 5k; R_0603_1608Metric
R19: 10k; R_0603_1608Metric
R21: 2.2k; R_0603_1608Metric
R22: 4.3k; R_0603_1608Metric
R23, R24: 10K; R_0603_1608Metric
SENSOR_IN1: SENSOR_OUT; RJ45_NEW
U6: LM317_SOT-223; SOT-223-3_TabPin2
U12: SSP7901P33MR; SOT-23-3

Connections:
/Sensor Board/3.7V: C13.1, OPTICAL_SMOKE1.5 (VCC), R21.1, U6.2 (VO)
/Sensor Board/3V: C23.1, C25.1, JP2.2 (B), MEMS_SMOKE1.2 (VCC), R23.1, R24.1, U12.2 (VOUT)
/Sensor Board/5V: C22.1, JP1.1 (A), MQ1.1 (VCC), POWER_IN1.4, U12.3 (VIN)
/Sensor Board/9V: ELECBEE1.2 (+9V), POWER_IN1.2, U6.3 (VI)
/Sensor Board/12-24V_IN: J4.1, POWER_IN1.5
/Sensor Board/ALARM: ELECBEE1.4 (CO), OPTICAL_SMOKE1.1 (ALARM), SENSOR_IN1.3
/Sensor Board/GND: BME1.3 (GND), C13.2, C22.2, C23.2, C25.2, ELECBEE1.1 (GND), ELECBEE1.5 (NC), J4.3, MEMS_SMOKE1.3 (GND), MQ1.2 (GND), OPTICAL_SMOKE1.4 (GND), OPTICAL_SMOKE1.MP, POWER_IN1.1, R19.2, R22.2, SENSOR_IN1.8, SENSOR_IN1.SH, U12.1 (GND)
/Sensor Board/MEMS_AOUT: MEMS_SMOKE1.1 (A), SENSOR_IN1.1
/Sensor Board/MQ2_DO: R18.2, R19.1, SENSOR_IN1.2
/Sensor Board/MUTE: OPTICAL_SMOKE1.2 (MUTE), SENSOR_IN1.4
/Sensor Board/SCL: BME1.4 (SCK), R23.2, SENSOR_IN1.6
/Sensor Board/SDA: BME1.6 (SDI), R24.2, SENSOR_IN1.7
/Sensor Board/WS2811: J4.2, SENSOR_IN1.5
unnamed: BME1.2 (3V), JP2.1 (A)
unnamed: BME1.1 (VIN), JP1.2 (B)
unnamed: MQ1.4 (AO), R18.1
unnamed: R21.2, R22.1, U6.1 (ADJ)

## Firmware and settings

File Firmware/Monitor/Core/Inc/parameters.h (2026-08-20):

/*
 * CLURA ENCLOSURE - RevB firmware
 */

#ifndef INC_PARAMETERS_H_
#define INC_PARAMETERS_H_
#include<stdio.h>
#include <cstdint>         // For uint8_t
#include <cstdio>

// Physical flap travel is a 39 deg swing: 5 deg = OPEN, 44 deg = CLOSED.
// All commanded angles MUST stay within [5, 44] or the servo drives into a hard stop.
// The value 0 is RESERVED as SERVO_OFF (see below), so every real position stays > 0.
// NOTE: these are only defaults - servoOpenAngle / servoCloseAngle in data.clu
// override them at runtime, so the two must describe the same orientation.
#define OPEN_ANGLE       5   // fully-open / vent position
#define CLOSE_ANGLE       44   // closed position

// Manual-mode sentinel: ms.servoAngle == SERVO_OFF means "servo off / not manually positioned".
// In this state the fan-page OPEN/CLOSE button is authoritative (ms.fanServoState).
#define SERVO_OFF         0
#define SERVO_TEMP_HYST   3   // deg C hysteresis for the overtemp vent-open safety
#define SERVO_HOLD_MS     600 // ms to drive the flap before detaching (travel ~450 ms + margin)

#define EXTRA_FAN_SPEED 75 // %, fixed speed of the regulated "extra" fan when on
#define MIN_BRIGHTNESS 15

#define DEFAULT_LEFT_CAL 740
#define DEFAULT_RIGHT_CAL 740
#define DEFAULT_LEFT_OFFSET 8483528
#define DEFAULT_RIGHT_OFFSET 8483528
#define TARE_WEIGHT 1000 // filament weight
#define NUM_OF_FILAMENTS 24
#define LEN_BUFFER 16

/* Fire response. While smoke or gas is detected: stop every fan AND close the
 * flap, so the enclosure starves a fire of oxygen instead of ventilating it.
 * Deliberately outranks the overtemp vent-open - see applyServoControl().
 * 1 = enabled (default). */
#define SMOKE_FIRE_RESPONSE 1

/* Optical smoke sensor -> alarm. Default 0 (deactivated): the sensor input
 * is configured with a pull-up and reads HIGH = "smoke", so a missing or
 * disconnected sensor floats high and would hold the alarm on permanently.
 * Set opticalAlarmEnable = 1 in data.clu once a sensor is fitted. */
#define OPTICAL_ALARM_ENABLE 0

#define LPG_THRESHOLD 2000//MQ2
#define SMOKE_THRESHOLD 750//MEMS
#define COUNTDOWN_TIME 5
#define SMOKE_BEGIN_TIME 300000 //milliseconds

#define MAX_TEMP 55 // deg C: flap forced open above this (see maxTemp in data.clu, 35..80)

#define AUTOCOOL_TEMP_MIN 20
#define AUTOCOOL_TEMP_MAX 40
#define AUTOFILTER_IMPURITIES_MIN 5
#define AUTOFILTER_IMPURITIES_MAX 100
#define AUTOFILTER_P03_MIN 100
#define AUTOFILTER_P03_MAX 2000
/* Filter/sensor replacement warning, in HOURS of filter-fan runtime.
 * Expressed in hours to match the usage figure shown on the settings page
 * (which divides usage_minutes by 60). 300 h = the previous 18000 min. */
#define SENSOR_USAGE_WARNING_HOURS 300

#define BME_SAMPLE_INTERVAL 5000
#define GAS_SAMPLE_INTERVAL_MS 250 // ms between MQ2/MEMS ADC sample bursts
#define USAGE_LOG_INTERVAL 900000 // 15 min between usage saves (EEPROM wear)
#define NOT_FOUND -404

// EEPROM (AT24C256 — 32 KB, I²C, A2/A1/A0 all open → address 0x50)
#define EEPROM_I2C_ADDR              0x50U   /**< 7-bit I²C address                      */
#define EEPROM_PAGE_SIZE             64U     /**< Write page size in bytes                */
#define EEPROM_WRITE_DELAY_MS        6U      /**< Write-cycle wait time (datasheet: 5 ms) */
#define EEPROM_CAPACITY_BYTES        32768U  /**< Total capacity (AT24C256)               */

// EEPROM memory map
#define EEPROM_MAGIC_VALUE           0xC1A4U /**< Sentinel to detect valid data           */
#define EEPROM_CONFIG_VERSION        1U      /**< Increment when EepromConfig layout changes */
#define EEPROM_ADDR_MAGIC            0x0000U /**< uint16_t magic word       (2 B)         */
#define EEPROM_ADDR_VERSION          0x0002U /**< uint16_t config version   (2 B)         */
#define EEPROM_ADDR_CONFIG           0x0004U /**< EepromConfig struct       (~73 B)       */
#define EEPROM_ADDR_FILAMENT_BRAND   0x0080U /**< char[24][16] brand names  (384 B)       */
#define EEPROM_ADDR_FILAMENT_WEIGHT  0x0200U /**< int32_t[24] spool weights (96 B)        */
/* Runtime tuning block (see tuning.h). Deliberately placed well clear of the
 * filament weights (which end at 0x0260) and given its own magic/version/CRC,
 * so the existing config block needs no migration and no version bump. */
/* Boot counter for the CSV log. Its own address so incrementing it each boot
 * never rewrites the config or tuning blocks. */
#define EEPROM_ADDR_BOOTID           0x0280U /**< EepromBootId struct       (6 B)         */
/* Machine-usage counter. Its own record so persisting it never rewrites the
 * 73-byte config block (which was wearing the EEPROM out in ~115 days). */
#define EEPROM_ADDR_USAGE            0x0290U
/* Revision of the filament library last imported from filament.clu. Own record
 * so writing it never disturbs the config, usage or tuning blocks. */
#define EEPROM_ADDR_FILAMENT_REV     0x02A0U

#define EEPROM_ADDR_TUNING           0x0300U /**< EepromTuning struct       (~72 B)       */

// PATHS  (SD card — logging and OTA only)
#define CSV_PATH "log.csv"
#define CONFIG_PATH "data.clu"
#define FILAMENT_PATH  "filament.clu"

// COMMAND CODES TYPES
#define BACK   0
#define OK     1
#define CANCEL 2
#define SLIDER 3
#define BUTTON 4

// PAGES
#define SETTINGS 0
#define HOMESCREEN 1
#define LIGHTING 2
#define FANCTRL 3
#define SPOOLHOLDERS 4
#define SENSORS 5
#define OUTPUT_CTRL 6
#define SUPPORT 7
#define LNDSCREEN 8
#define LNDSCREEN2 9
#define CHOOSE_CONFIG 10
#define FEATURES 11
#define SYS_CHECK 12
#define SELECTOR 13
#define CAL_SEQUENCE1 14
#define CAL_SEQUENCE2 15
#define CAL_SEQUENCE3 16
#define CAL_SEQUENCE4 17
#define CAL_FINISH_PAGE 18
#define CALIBRATE1 19
#define CALIBRATE2 20
#define CALIBRATE3 21
#define CALIBRATE4 22
#define CONFIG_SAVE_FAIL 23
#define CALIBRATION_SAVE_SUCCESS 24
#define CALIBRATION_SAVE_FAIL 25
#define FORMAT_SUCCESS 26
#define FORMAT_FAIL 27

#define UPDATE_PAGE1 31
#define UPDATE_PASS 32
#define UPDATE_FAIL 33

// IMAGE IDs For the Check status on the Settings Page
#define MUTE 144
#define UNMUTE 149
#define ALARM 155
#define NO_ALARM 156
#define SENSOR_SAFE_PIC 146
#define SENSOR_UNSAFE_PIC 145
// IMAGE IDs For the Check status on the sensors Page
#define INTERVAL_ON 44
#define INTERVAL_OFF 45
#define MIN_5_LOG 46
#define MIN_10_LOG 47
#define MIN_60_LOG 48

// IMAGE IDs For the Check status on the system check Page
#define SUCCESS_IMAGE_ID 108
#define FAIL_IMAGE_ID 107
#define RUNNING_IMAGE_ID 106
#define NULL_IMAGE_ID 105

// IMAGE IDs For the Features Selection Page
#define PMS_IMAGE_ID 79
#define BME_IMAGE_ID 80
#define OPTICAL_SMOKE_SENSOR_IMAGE_ID 81
#define MQ2_IMAGE_ID 82
#define LOAD_CELL_IMAGE_ID 83
#define FILTER_FAN_IMAGE_ID 84
#define COOLING_FAN_IMAGE_ID 85
#define RGB_LED_IMAGE_ID 86
#define LED_STRIP_IMAGE_ID 87

// IMAGE IDs For the selected Features on the Selection Page
#define SELECTED_PMS_IMAGE_ID 88
#define SELECTED_BME_IMAGE_ID 89
#define SELECTED_OPTICAL_SMOKE_SENSOR_IMAGE_ID 90
#define SELECTED_MQ2_IMAGE_ID 91
#define SELECTED_LOAD_CELL_IMAGE_ID 92
#define SELECTED_FILTER_FAN_IMAGE_ID 93
#define SELECTED_COOLING_FAN_IMAGE_ID 94
#define SELECTED_RGB_LED_IMAGE_ID 95
#define SELECTED_LED_STRIP_IMAGE_ID 96


//


typedef struct {
	bool mute;
	bool alarm;
	int standbyTime;
	int interval;
	bool logging;
	uint8_t brightness;
	int32_t leftSpoolWeight;
	int32_t rightSpoolWeight;
	int32_t temperatureBaseline;
	int32_t impuritiesBaseline;
	int32_t usage_minutes;

//filament and spool
	uint8_t leftSpoolIndex;
	uint8_t rightSpoolIndex;
	uint8_t leftSelectFilament;
	uint8_t rightSelectFilament;
	uint8_t filamentSelectPage;
	uint8_t filamentIndex;
	uint8_t filamentIndexMax;
	uint8_t filamentPage;
	uint8_t filamentPageMax;
	int  leftFilament;
	int  rightFilament;
	long leftCalFactor;
	long rightCalFactor;
	long leftOffset;
	long rightOffset;

	//filament and spool
	uint8_t Impurities;
	uint8_t lightIndex;
	float LedBrightness;
	uint8_t red;
	uint8_t blue;
	uint8_t green;
	bool ledBar;

	int filterFanASpeed;
	int filterFanBSpeed;
	uint8_t filterFanSetSpeed;
	uint8_t coolingFanSpeed;
	uint8_t coolingFanSetSpeed;
	bool autoCooling;
	bool manCooling;
	bool autoFiltering;
	bool manFiltering;
	bool isFanRegOn;

	int pm03;
	int pm2;
	int pm10;
	int pressure;
	int voc;
	int temperature;
	int HumidityBME;
	int HumidityPMS;
	int mqSmokeValue;
	int memsSmokeValue;

	//Servo
	uint8_t servoAngle;
	bool autoServo;
	bool servoPower;
	uint8_t fanServoState; // Fan page servo state (OPEN_ANGLE or CLOSE_ANGLE)

	bool relay;

	uint8_t features; //0:Regular,1:Pro,2:Custom
	bool usePms;
	bool useBme;
	bool useMq2;
	bool useOptical;
	bool useLedStrip;
	bool useLedBar;
	bool useLoadCell;
	bool useMems;
	bool useFilterFan;
	bool useCoolingFan;
	char qrUrl[64];
	bool calibrationComplete;
	uint8_t currentPage;
} MachineState;

extern MachineState ms;

extern char filamentBrand[NUM_OF_FILAMENTS][LEN_BUFFER];
extern int filamentWeight[NUM_OF_FILAMENTS];
#endif /* INC_PARAMETERS_H_ */

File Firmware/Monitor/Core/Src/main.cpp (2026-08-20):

/*
 * CLURA ENCLOSURE - RevB firmware
 */

/* Includes ------------------------------------------------------------------*/
#include "main.h"
#include "fatfs.h"

/* USER CODE BEGIN Includes */
#include "SmokeSensor.h"
#include "A_SmokeSensor.h"
#include "Servo.h"
#include "parameters.h"
#include "HX711.h"
#include "Screen.h"
#include "Motor.h"
#include "WS281x.h"
#include "Output.h"
#include <cstdio>
#include <string.h>
#include "bme680/bme68x_necessary_functions.h"
#include "debug_utils.h"
#include "eeprom_storage.h"
#include "tuning.h"
#include "filament_store.h"
#include "AT24C_EEPROM.h"
#include <stdio.h>
#include <string.h>
#include <stdarg.h>

#ifdef __cplusplus
extern "C" {
#endif
#include "fatfs.h"
#include "cJSON.h"
#ifdef __cplusplus
}
#endif
#define WAIT HAL_Delay(80)
#define AUTO_FAN_ACTION(autoButton,manButton,manSwitchtext,autoFlag,manFlag) \
        	tjc.setVal(autoButton, autoFlag);\
        	HAL_Delay(20);\
			tjc.setVal(manButton, manFlag);\
			HAL_Delay(20);\
			manFlag?tjc.setText(manSwitchtext, "ON"):tjc.setText(manSwitchtext, "OFF");\
			HAL_Delay(20);

#define SHOW_CONT_BTN   tjc.setAph("p8", 0);\
						tjc.setAph("p9", 0);\
						tjc.setAph("p10", 127);\
						tjc.setAph("p12", 0)
#define HIDE_CONT_BTN   tjc.setAph("p8", 127);\
						tjc.setAph("p9", 127);\
						tjc.setAph("p10", 0);\
						tjc.setAph("p12", 127)
/* USER CODE END Includes */

/* USER CODE BEGIN PM */

#define PMS_FRAME_LENGTH 32
#define SCREEN_BUFFER_SIZE 32
#define DATA_BUFFER_SIZE 20
#define LED_COUNT 100
#define MINUTE_CONST 60000 //TODO: Change back to 60000
/* USER CODE END PM */

ADC_HandleTypeDef hadc1;

I2C_HandleTypeDef hi2c1;

SPI_HandleTypeDef hspi2;

TIM_HandleTypeDef htim1;
TIM_HandleTypeDef htim2;
TIM_HandleTypeDef htim3;
TIM_HandleTypeDef htim5;
TIM_HandleTypeDef htim11;
DMA_HandleTypeDef hdma_tim1_ch1;

UART_HandleTypeDef huart1;
UART_HandleTypeDef huart2;

/* USER CODE BEGIN PV */

/* DATA BUFFERS  */
volatile uint8_t pms_data[PMS_FRAME_LENGTH]; // Buffer for pms_data frame
volatile uint8_t rxBuffer[SCREEN_BUFFER_SIZE];  // Buffer to store received data

uint8_t dataBuffer[DATA_BUFFER_SIZE];
uint8_t rxDataScreen;                 // Single-byte buffer for interrupt
uint8_t rxDataPms;                 // Single-byte buffer for interrupt
volatile uint16_t rxIndexScreen = 0;           // Current index in the buffer
volatile uint16_t rxIndexPms = 0;           // Current index in the buffer
volatile uint8_t dataReceivedScreen = 0;
volatile uint8_t dataReceivedPms = 0;
volatile uint8_t endCount = 0;

//uint8_t pulseReg = 60;
//uint8_t pulse60 = 60;
int8_t countdown = COUNTDOWN_TIME;         // WAIT TIMER BEFORE CONTINUE POPS UP
int osc_per_rev = 2;
bool refreshFlag = 1;
bool screenDimmed = false;
bool forceUpdate = true;

uint32_t standbyTimestamp = 0;
uint32_t dataLoggerTimestamp = 0;
/* Boot session id, read from EEPROM at startup. Logged with every CSV row so
 * rows stay orderable across power cycles (HAL_GetTick restarts at 0). */
uint32_t g_bootId = 1;
/* Actual commanded filter-fan speed (0-100). Set by every branch of the fan
 * control block, so it reflects auto AND manual mode - unlike
 * ms.filterFanSetSpeed, which only the manual slider ever writes. */
int filterFanDisplaySpeed = 0;

/* Overtemp latch, owned by applyServoControl() but read by the fan control
 * block, which runs later in the same pass. */
bool g_ventOpenOvertemp = false;

/* Machine-usage accounting. usage_minutes = g_usageBase + accumulated runtime.
 * Persisted in its own EEPROM record (see EEPROM_SaveUsage). */
uint32_t g_usageBase    = 0;   /* minutes already banked in EEPROM      */
uint32_t g_usageAccumMs = 0;   /* runtime accumulated since that base   */
uint32_t g_usageSaved   = 0;   /* last value actually written to EEPROM */


 bool alarm = 0;
bool refreshed_alarm = 0;
bool refresh_led_flag=1;
short coolingFanState = 0;
const int numOfButtons = 4;
int leftIDMaps[numOfButtons] = { 6, 8, 10, 12 }; //IDs of left check boxes to manage the states
int rightIDMaps[numOfButtons] = { 7, 9, 11, 13 }; //IDs of right check boxes to manage the states
int leftIDNums[numOfButtons] = { 0, 2, 4, 6, }; //Numbers of check boxes to manage the states
int rightIDNums[numOfButtons] = { 1, 3, 5, 7 }; //Numbers of check boxes to manage the states
volatile unsigned long filterFanACounter = 0;
volatile unsigned long filterFanBCounter = 0;
extern volatile bool ws281x_done;
bool sw = 0; //value to hold the switch state for the loop flap/gate
bool checkedPms = false;
bool checkedBme = false;
bool checkedOSS = false;
bool checkedMq2 = false;
bool checkedLC = false;
bool checkedFFan = false;
bool checkedCFan = false;
bool checkedRGB = false;
bool checkedLED = false;
bool runOnce = true;

bool bmeIsFound = false;



struct bme68x_data data;

typedef struct {
	uint16_t pm1_0_cf1;
	uint16_t pm2_5_cf1;
	uint16_t pm10_cf1;
	uint16_t pm1_0_atm;
	uint16_t pm2_5_atm;
	uint16_t pm10_atm;
	uint16_t particles_0_3;
	uint16_t particles_0_5;
	uint16_t particles_1_0;
	uint16_t particles_2_5;
	uint16_t particles_5_0;
	uint16_t particles_10;
} PmsData;

PmsData pms_info { 0 };

/* PERIPHERAL OBJECTS   */

HX711 loadCellLeft(HX1DT_GPIO_Port, HX1DT_Pin, HX1SCK_GPIO_Port, HX1SCK_Pin);
HX711 loadCellRight(HX2DT_GPIO_Port, HX2DT_Pin, HX2SCK_GPIO_Port, HX2SCK_Pin);
SmokeSensor smokeSensor(ALARM_GPIO_Port, ALARM_Pin, MUTE_GPIO_Port, MUTE_Pin);
A_SmokeSensor mqSensor( MQ2_GPIO_Port, MQ2_Pin, &hadc1, ADC_CHANNEL_6);
A_SmokeSensor memsSensor( MEMS_SMOKE_GPIO_Port, MEMS_SMOKE_Pin, &hadc1,
ADC_CHANNEL_7);
Servo servo(&htim5, TIM_CHANNEL_1);
Output ssr1(SSR1_GPIO_Port, SSR1_Pin);
Output ssr2(SSR2_GPIO_Port, SSR2_Pin);
Output buzzer(BUZZER_GPIO_Port, BUZZER_Pin);
Screen tjc(&huart2);

Motor coolingFan(&htim3, 3);
Motor filterFan(&htim3, 4);
Motor fanReg(&htim2, 3);

WS281x ledStrip(&htim1, TIM_CHANNEL_1);
ScreenEvent event;

// RUNTIME PARAMS
char debugBuffer[128];
bool recievingPms = false;
bool saveFlag = false; //save config? this is a runtime variable do not modify
int leftCalWeight = 1200; // weight variable read by the sensor during the calibration
int rightCalWeight = 1200;
int customSpoolWeight = 0;
uint32_t smokeBeginTimestamp = 0;
uint32_t BME_Timestamp = 0;
/* USER CODE END PV */

void SystemClock_Config(void);
static void MX_GPIO_Init(void);
static void MX_DMA_Init(void);
static void MX_USART1_UART_Init(void);
static void MX_USART2_UART_Init(void);
static void MX_I2C1_Init(void);
static void MX_TIM2_Init(void);
static void MX_TIM3_Init(void);
static void MX_TIM5_Init(void);
static void MX_ADC1_Init(void);
static void MX_SPI2_Init(void);
static void MX_TIM1_Init(void);
static void MX_TIM11_Init(void);
/* USER CODE BEGIN PFP */
bool isValidPmsData(volatile uint8_t *buffer, int size);
bool readBme();
void debug_pms_data(PmsData *data);
void process_pms_data(volatile uint8_t *buffer, PmsData *data);
void handleHomeScreen(ScreenEvent event);
void handleFanControl(ScreenEvent event);
void handleSensors(ScreenEvent event);
void handleSpoolHolders(ScreenEvent event);
void handleOutput(ScreenEvent event);
void handleLighting(ScreenEvent event);
void handleSupport(ScreenEvent event);
void handleLndScreen2(ScreenEvent event);
void handleConfig(ScreenEvent event);
void handleCustomFeatures(ScreenEvent event);
void handleSystemCheck(ScreenEvent event);
void handleSelector(ScreenEvent event);

void handleCalSequence1(ScreenEvent event);
void handleCalSequence2(ScreenEvent event);
void handleCalSequence3(ScreenEvent event);
void handleCalSequence4(ScreenEvent event);

void handleCalibrate1(ScreenEvent event);
void handleCalibrate2(ScreenEvent event);
void handleCalibrate3(ScreenEvent event);
void handleCalibrate4(ScreenEvent event);

void handleDone(ScreenEvent event);
void handleSettings(ScreenEvent event);
void handleConfigSaveFail(ScreenEvent event);
void handleCalibrationSaveFail(ScreenEvent event);
void handleCalibrationSaveSuccess(ScreenEvent event);
void handlePageEvent(ScreenEvent event);
void handleFormatFail(ScreenEvent event);
void handleFormatSuccess(ScreenEvent event);

float constrain(float val, float min, float max);
void runMachine(void);
void applyServoControl(void);
void updateUsageCounter(void);
bool csvInit(void);
bool csvLog(uint32_t bootId, int t, int temperature, int humidity, int pressure, int smoke,int pm03,
		int pm2_5, int pm10, int voc, int lpg,int fanSpd,int lWeight, int rWeight);
/* SD card: csvDelete used by handleSensors (format button) */
bool csvDelete(void);
/* USER CODE END PFP */

/* USER CODE BEGIN 0 */

/* D-20: one file-scope FATFS shared by the csv helpers.
 * f_mount() stores this pointer in FatFs' internal drive table and keeps using
 * it after the call returns, so the stack-local FATFS each of these used to
 * declare left a dangling pointer the moment the function exited. It only ever
 * worked because every one of them re-mounts before touching the card - a trap
 * for any future code that does not. */
static FATFS s_csvFatFs;

bool csvInit(void) {
	FATFS &FatFs = s_csvFatFs;
	FIL file;
	FRESULT fres;
	//check if log is in sd car d
	fres = f_mount(&FatFs, "", 1);
	if (fres != FR_OK)
		return false;
	fres = f_open(&file, CSV_PATH, FA_READ);
	if (fres != FR_OK) {
		//create if not in sd card
		fres = f_open(&file, CSV_PATH, FA_WRITE | FA_CREATE_ALWAYS);
		if (fres == FR_OK) {
			UINT bw;

			// **FIXED LINE:**
			// Reordered the header to match the csvLog function's parameters
			const char *header =
					"BootID,MinSinceBoot,Temperature,Humidity,Pressure,Smoke,PM 0.3,PM 2.5,PM 10,VOC,LPG,Fan Speed,Left Weight,Right Weight\n";

			f_write(&file, header, strlen(header), &bw);
			f_close(&file);
			return true;

		}
	} else {
		f_close(&file);
		return true;

	}
	return false;
}
bool csvDelete(void) {
	FATFS &FatFs = s_csvFatFs;
	FIL file;
	FRESULT fres;
	//check if log is in sd car d
	fres = f_mount(&FatFs, "", 1);
	if (fres != FR_OK)
		return false;
	fres = f_open(&file, CSV_PATH, FA_READ);
	if (fres == FR_NO_FILE) {
		return true;
	}
	fres = f_close(&file);
	fres = f_unlink(CSV_PATH);
	if (fres == FR_OK) {
		return true;
	}
	return false;
}
bool csvLog(uint32_t bootId, int t, int temperature, int humidity, int pressure, int smoke, int pm03,
		int pm2_5, int pm10, int voc, int lpg, int fanSpd, int lWeight, int rWeight) {
	FATFS &FatFs = s_csvFatFs;

	FIL file;
	FRESULT fres;
	UINT bw;
	char line[256];
	fres = f_mount(&FatFs, "", 1);
	if (fres != FR_OK)
		return false;
	// Open the CSV file in append mode
	fres = f_open(&file, CSV_PATH, FA_WRITE | FA_OPEN_APPEND);
	if (fres == FR_OK) {
		// **FIXED LINE:**
		// Updated to include all 13 parameters in the correct order.
		/* D-14: `smoke` and `lpg` used to be written the other way round, so the
		 * Smoke column carried MQ2 gas readings and the LPG column carried MEMS
		 * smoke readings. Rows logged before this change stay swapped. */
		snprintf(line, sizeof(line), "%lu,%d,%d,%d,%d,%d,%d,%d,%d,%d,%d,%d,%d,%d\n",
				(unsigned long)bootId, t, temperature, humidity, pressure, smoke, pm03,
				pm2_5, pm10, voc, lpg, fanSpd, lWeight, rWeight);

		f_write(&file, line, strlen(line), &bw);
		f_close(&file);
		return true;

	}
	return false;

}


/* ──────────────────────────────────────────────────────────────────────────
 * NOTE: saveConfig / loadConfig / saveFilamentData / loadFilamentData
 *       have been removed.  Config and filament data are now stored on the
 *       AT24C256 EEPROM via EEPROM_SaveConfig / EEPROM_LoadConfig /
 *       EEPROM_SaveFilamentData / EEPROM_LoadFilamentData (eeprom_storage.cpp).
 *
 *       SD card is retained ONLY for:
 *         • csvInit / csvLog / csvDelete  (sensor data logging)
 *         • OTA firmware binary           (reserved, future use)
 * ────────────────────────────────────────────────────────────────────────── */

void handlePageEvent(ScreenEvent event) {


	switch (event.pageNumber) {
	case HOMESCREEN:
		handleHomeScreen(event);
		break;
	case FANCTRL:
		handleFanControl(event);
		break;
	case SENSORS:
		handleSensors(event);
		break;
	case SPOOLHOLDERS:
		handleSpoolHolders(event);
		break;
	case LIGHTING:
		handleLighting(event);
		break;
	case SETTINGS:
		handleSettings(event);
		break;
	case OUTPUT_CTRL:
		handleOutput(event);
		break;
	case SUPPORT:
		handleSupport(event);
		break;
	case LNDSCREEN2:
		handleLndScreen2(event);
		break;
	case CHOOSE_CONFIG:
		handleConfig(event);
		break;
	case FEATURES:
		handleCustomFeatures(event);
		break;
	case SYS_CHECK:
		handleSystemCheck(event);
		break;
	case SELECTOR:
		handleSelector(event);
		break;
	case CAL_SEQUENCE1:
		handleCalSequence1(event);
		break;
	case CAL_SEQUENCE2:
		handleCalSequence2(event);
		break;
	case CAL_SEQUENCE3:
		handleCalSequence3(event);
		break;
	case CAL_SEQUENCE4:
		handleCalSequence4(event);
		break;
	case CAL_FINISH_PAGE:
		handleDone(event);
		break;
	case CALIBRATE1:
		handleCalibrate1(event);
		break;
	case CALIBRATE2:
		handleCalibrate2(event);
		break;
	case CALIBRATE3:
		handleCalibrate3(event);
		break;
	case CALIBRATE4:
		handleCalibrate4(event);
		break;
	case CALIBRATION_SAVE_FAIL:
		handleCalibrationSaveFail(event);
		break;
	case CALIBRATION_SAVE_SUCCESS:
		handleCalibrationSaveSuccess(event);
		break;
	case CONFIG_SAVE_FAIL:
		handleConfigSaveFail(event);
		break;
	case FORMAT_FAIL:
			handleFormatFail(event);
			break;
	case FORMAT_SUCCESS:
		handleFormatSuccess(event);
			break;
		break;
	}
}

//------------------------------------CALIBRATION--------------------------------------

float constrain(float val, float min, float max) {
	if (val < min) {
		val = min;
	} else if (val > max) {
		val = max;
	}
	return val;
}
//------------------------------------HOMESCREEN------------------------------------
void handleHomeScreen(ScreenEvent event) {
	switch (event.objectID) {
	case 2:
		tjc.setPage(OUTPUT_CTRL, ms);
		break;
	case 3:
		tjc.setPage(SETTINGS, ms);
		break;
	case 4:
		tjc.setPage(FANCTRL, ms);
		break;
	case 6:
		tjc.setPage(LIGHTING, ms);
		break;
	case 5:
		tjc.setPage(SPOOLHOLDERS, ms);
		break;
	case 7:
		tjc.setPage(SENSORS, ms);
		break;
	default:
		break;
	}
forceUpdate =true;
}
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
int main(void)
{

  /* MCU Configuration--------------------------------------------------------*/

  /* Reset of all peripherals, Initializes the Flash interface and the Systick. */


  /* Reset of all peripherals, init the Flash interface and the Systick. */
  HAL_Init();

  /* Configure the system clock */
  SystemClock_Config();
  /* Initialize all configured peripherals */
  MX_GPIO_Init();
  MX_DMA_Init();
  MX_USART1_UART_Init();
  MX_USART2_UART_Init();
  MX_I2C1_Init();
  MX_TIM2_Init();
  MX_TIM3_Init();
  MX_TIM5_Init();
  MX_ADC1_Init();
  MX_FATFS_Init();
  MX_SPI2_Init();
  MX_TIM1_Init();
  MX_TIM11_Init();
  /* USER CODE BEGIN 2 */
  __enable_irq();
	HAL_UART_Receive_IT(&huart1, &rxDataPms, 1);
	HAL_UART_Receive_IT(&huart2, &rxDataScreen, 1);
	HAL_TIM_PWM_Start(&htim2, TIM_CHANNEL_3);
	HAL_TIM_PWM_Start(&htim3, TIM_CHANNEL_3);
	HAL_TIM_PWM_Start(&htim3, TIM_CHANNEL_4);
	HAL_TIM_Base_Start_IT(&htim11);

//	HAL_Delay(1000);

	/* ── EEPROM boot sequence ────────────────────────────────────────────────
	 *
	 * Step 1: Check that the EEPROM responds on the I²C bus.
	 *         If it doesn't reply at the default address (0x50), scan all
	 *         possible AT24C addresses (0x50–0x57) — open/floating address
	 *         pins can settle at VCC giving address 0x57.
	 *
	 * Step 2: If no device found at all, skip EEPROM and use compile-time
	 *         defaults. The system works normally but settings won't persist
	 *         across power cycles until the wiring is fixed.
	 *
	 * Step 3: Check the magic word. If missing (brand-new or erased chip),
	 *         write the magic + compile-time defaults (first-boot format).
	 *         Otherwise load the saved config and filament data.
	 *
	 * ─────────────────────────────────────────────────────────────────────── */
	if (!EEPROM_IsReady())
	{
		/* Not at 0x50 — scan the whole range */
		uint8_t found = EEPROM_ScanAddress();   /* also updates g_eeprom_addr */
		(void)found;   /* suppress unused-variable warning */
		/* If scan also fails, g_eeprom_addr is reset to 0x50 and
		 * all subsequent EEPROM calls will return HAL_ERROR gracefully. */
	}

	/* Runtime tuning: load the block from EEPROM (or defaults / migrate), then
	 * apply data.clu from the SD card if it carries a newer configRevision.
	 * Must run before anything reads g_tune. Safe with no EEPROM and/or no SD. */
	/* Boot session id for the CSV log. Read+incremented once per power-on. */
	g_bootId = EEPROM_NextBootId();

	Tuning_Init();

	if (EEPROM_IsReady())
	{
		if (!EEPROM_IsValid())
		{
			/* First boot or blank/erased chip — write magic and defaults */
			EEPROM_Format(&ms, filamentBrand, filamentWeight);
		}
		else
		{
			/* Normal boot — load persistent config and filament data */
			for (int var = 0; var < 3; ++var) {
				if (EEPROM_LoadConfig(&ms)) break;
			}
			/* Sanitize stale servo state from EEPROM (old firmware could have saved
			 * autoServo=true or an out-of-range fanServoState, which would disable the
			 * fan button or drive the servo into a hard stop at boot). */
			ms.autoServo = false;
			if (ms.fanServoState != g_tune.servoOpenAngle && ms.fanServoState != g_tune.servoCloseAngle) {
				ms.fanServoState = g_tune.servoCloseAngle;
			}
			for (int var = 0; var < 3; ++var) {
				if (EEPROM_LoadFilamentData(filamentBrand, filamentWeight)) break;
			}
			/* Reconcile with the SD card: create filament.clu if it is missing,
			 * or import it if a technician has raised its filamentRevision. */
			Filament_Init(filamentBrand, filamentWeight, &ms.filamentIndexMax);
		}
	}
	/* else: EEPROM not found — continue with compile-time defaults */

	/* Restore the gate/flap switch state from the persisted servo state */
	sw = (ms.fanServoState == g_tune.servoOpenAngle);

	/* Load-cell seeds for a board that has never been calibrated.
	 *
	 * ms.calibrationComplete is the authoritative flag: it starts false (see
	 * parameters.cpp), is set true ONLY at the end of the calibration wizard
	 * (handleDone), and is persisted in EEPROM. So "false" means this unit has
	 * never completed calibration and its cal factors are placeholders.
	 *
	 * In that state, seed from the tuning block so the values can be adjusted
	 * per production batch via data.clu instead of requiring a rebuild. Once a
	 * unit is calibrated the flag latches true and its measured factors are
	 * never overwritten - changing these in data.clu will not disturb it. */
	if (!ms.calibrationComplete) {
		ms.leftCalFactor  = g_tune.defaultLeftCal;
		ms.rightCalFactor = g_tune.defaultRightCal;
		ms.leftOffset     = g_tune.defaultLeftOffset;
		ms.rightOffset    = g_tune.defaultRightOffset;
	}

	loadCellLeft.init();
	loadCellLeft.setScale(ms.leftCalFactor);
	loadCellLeft.setOffset(ms.leftOffset);

	loadCellRight.init();
	loadCellRight.setScale(ms.rightCalFactor);
	loadCellRight.setOffset(ms.rightOffset);

	smokeSensor.begin();
	mqSensor.begin();
	memsSensor.begin();
	ssr1.begin();
	ssr2.begin();
	buzzer.begin();
	tjc.setDim(35);
	if (ms.calibrationComplete) {
		tjc.setPage(LNDSCREEN, ms); //TODO: CHANGE BACK TO  LNDSCREEN
		HAL_Delay(2000);
		tjc.setPage(HOMESCREEN, ms);//TODO: CHANGE BACK TO  HOMESCREEN
	} else {
		tjc.setPage(LNDSCREEN2, ms);//TODO: CHANGE BACK TO  LNDSCREEN2

	}
	tjc.setDim(ms.brightness);

//-----------------------------------------------------------------------------

	if (HAL_I2C_IsDeviceReady(&hi2c1, 0x76 << 1, 5, 1000) == HAL_OK) {
		bmeIsFound = true;
	} else if (HAL_I2C_IsDeviceReady(&hi2c1, 0x77 << 1, 5, 1000) == HAL_OK) {
		bmeIsFound = true;
	} else {
		bmeIsFound = false;
	}

	bme68x_start(&data, &hi2c1);

  /* USER CODE END 2 */

  /* Infinite loop */
  /* USER CODE BEGIN WHILE */
	servo.start(); // servo left idle (no pulse) until the fan button commands it
 BME_Timestamp = smokeBeginTimestamp = dataLoggerTimestamp = HAL_GetTick();
 standbyTimestamp = HAL_GetTick(); // start the standby timer from boot (it inits to 0 → would dim early)

	/* Machine usage. The dedicated record is authoritative; if it is absent
	 * (first boot on this firmware) seed it from the value that was carried in
	 * the config block, so no accumulated history is lost. */
	{
		uint32_t stored = 0;
		if (!EEPROM_LoadUsage(&stored)) {
			stored = (ms.usage_minutes > 0) ? (uint32_t)ms.usage_minutes : 0u;
			(void)EEPROM_SaveUsage(stored);
		}
		g_usageBase      = stored;
		g_usageSaved     = stored;
		g_usageAccumMs   = 0;
		ms.usage_minutes = (int32_t)stored;
	}
	while (1)

	{
		runMachine();

		updateUsageCounter();

		if (ms.logging) {

			uint32_t logTime = 0;
			if (ms.interval == 5) {
				logTime = 5*60000;
			} else if (ms.interval == 10) {
				logTime = 10 * 60000;
			} else {
				logTime = 60 * 60000;
			}

			if (HAL_GetTick() - dataLoggerTimestamp >= logTime) {
				if (csvInit()) {
					int t = HAL_GetTick() / 60000;

					long lw =ms.useLoadCell?loadCellLeft.getWeight():NOT_FOUND;
					long rw =ms.useLoadCell?loadCellRight.getWeight():NOT_FOUND;

					/* Log the ACTUAL commanded fan speed, not ms.filterFanSetSpeed -
					 * only the manual slider writes that field, so in auto mode
					 * the log recorded 0% while the fan was running. Same root
					 * cause as the usage-counter gating. */
					csvLog(g_bootId, t, ms.temperature, ms.HumidityBME, ms.pressure,
							ms.memsSmokeValue,ms.pm03, ms.pm2, ms.pm10, ms.voc,
							ms.mqSmokeValue,filterFanDisplaySpeed,lw,rw);
					dataLoggerTimestamp = HAL_GetTick();
				}

			}
		}
		if (saveFlag) {
			EEPROM_SaveConfig(&ms);
			saveFlag = false;
		}
		if (dataReceivedScreen == 1) {
			char tempBuffer[SCREEN_BUFFER_SIZE];
			__disable_irq();
			memcpy(tempBuffer, (const uint8_t*) rxBuffer, SCREEN_BUFFER_SIZE);
			dataReceivedScreen = 0;
			__enable_irq();
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

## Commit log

2026-01-13 Upload files with LFS for large STEP files
    [1X_3mm_Black_BambuBackPanelElectronics.dxf, 1X_3mm_Black_BambuBackPanelFront.dxf, 1X_3mm_Black_BambuTopPanelElectronics.dxf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]
2026-08-08 PCB & FIRMWARE Final files
    [BOM_FINAL_MAINBOARD.xlsx, BOM_FINAL_SENSORBOARD.xlsx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]
2026-08-20 Full Rework - final files
    [1X_3mm_Black_BambuBackPanelElectronics.dxf, 1X_3mm_Black_BambuBackPanelFront.dxf, 1X_3mm_Black_BambuTopPanelElectronics.dxf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]
2026-09-11 Updated PC4 Fittings
    [1x_Handle_L_PTFE.3mf, 1x_Handle_R_PTFE.3mf, 1x_L_Spool_holder_part_1.3mf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]
